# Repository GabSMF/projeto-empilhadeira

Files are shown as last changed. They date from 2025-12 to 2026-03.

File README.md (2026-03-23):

# Robotics - Autonomous Fork-Lif Project
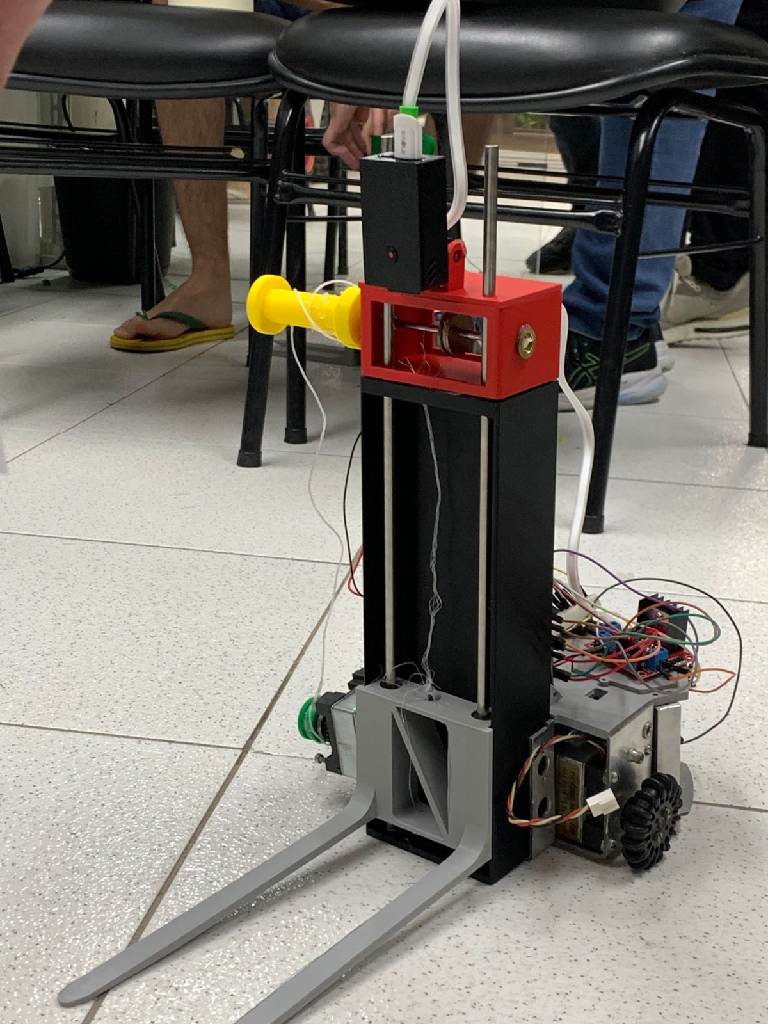
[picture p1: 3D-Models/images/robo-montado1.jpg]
robo montado irl


## 3D Pieces
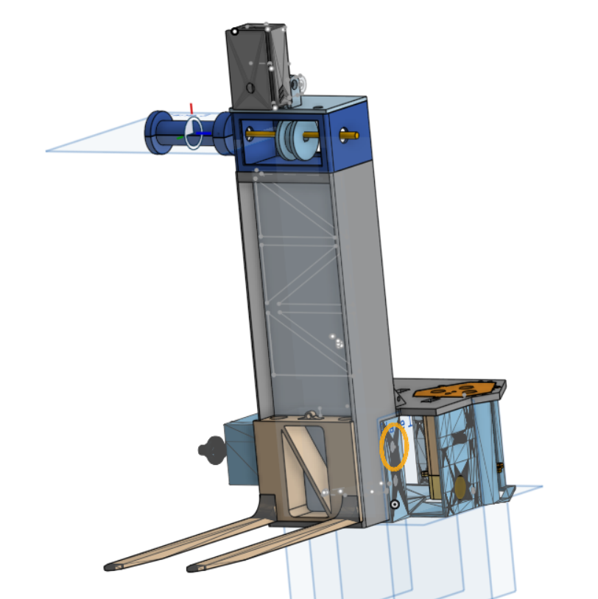
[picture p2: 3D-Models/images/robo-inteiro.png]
robo inteiro 3d


### 1. Chassis Cover

The **chassis cover** is the central interface piece between the metal chassis and the 3D printed modules.

**Function and characteristics:**
- Fixed directly to the **metal chassis** using screws.
- Has **2 holes** for fitting the **battery holders** (battery cases).
- On the front, there is a **protrusion/overlap** where the connection with the **elevator guide** is made, through **3 holes** for screws that ensure the guide is fixed.
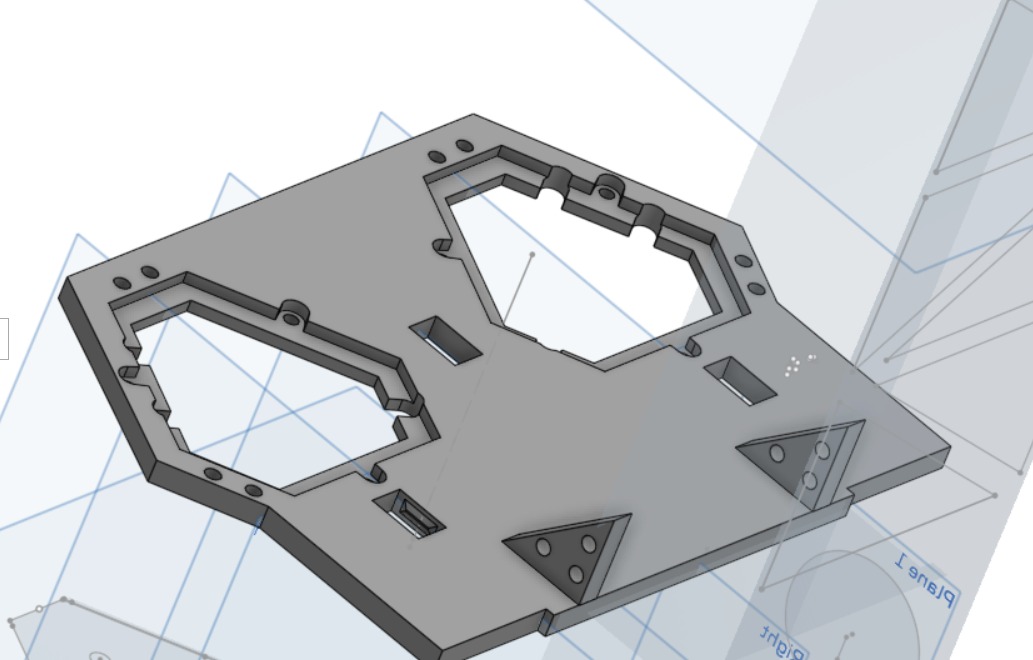
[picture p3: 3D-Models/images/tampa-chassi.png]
Tampa

---

### 2. Fork Guide

The **fork guide** is responsible for guiding the vertical movement of the fork along the **Y** axis.

**Function and characteristics:**
- It has slots for **2 metal cylinders** that function as **guide shafts**.
- The fork uses **linear bearings** (minimum 2, 6 mm inner diameter) that slide on these shafts.
- On the top, there is:
  - A **hole for the passage of the wire/cable** coming from the pulley.
  - Slots for the **pulley housing**, which houses the pulley and the shaft.
  - On the lower side there is a region intended for fixing the **lateral motor**, responsible for driving the fork pulley (see photos of the assembled robot for reference).

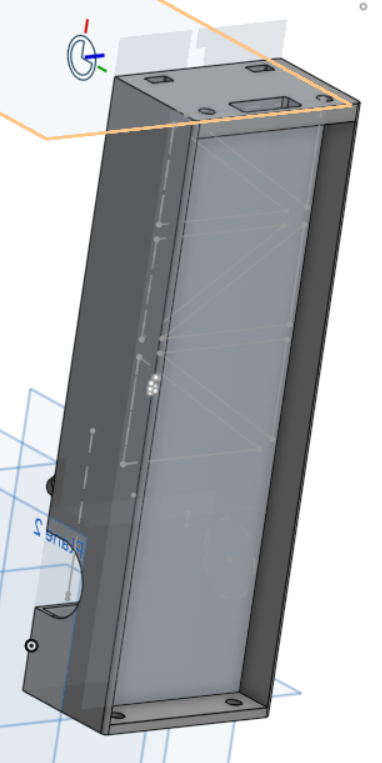
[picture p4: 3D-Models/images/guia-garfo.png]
Guia Garfo

---

### 3. Fork

The **fork** is the component that effectively interacts with the pallet, performing the loading.

**Function and characteristics:**
- It has **vertical sections** for fitting at least **2 linear bearings**, which allow smooth sliding on the guide axes.
- It includes a **specific region for tying/fixing the pulley cable**, responsible for raising and lowering the fork.

**Points observed / future improvements:**
- The **height of the fork**, in the current configuration, is **above the height of the pallet**, which may hinder ideal fitting.
- The **thickness of the fork** is relatively **thin**, which may compromise robustness and mechanical resistance.
- Suggested improvements: reinforce the cross-section and adjust the height to better align with the height of the pallet.
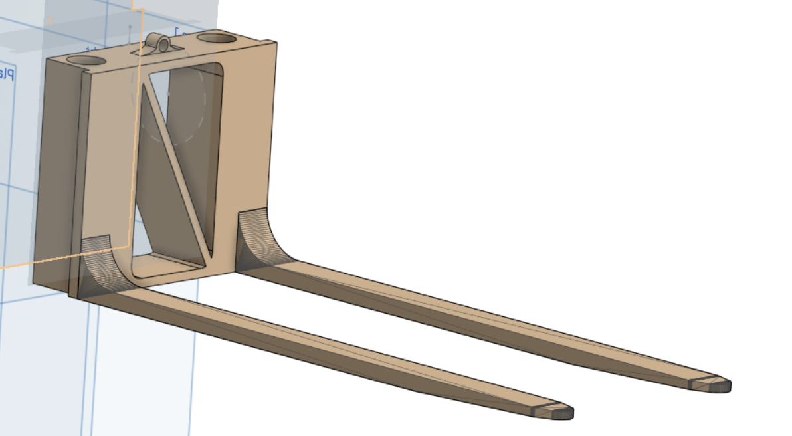
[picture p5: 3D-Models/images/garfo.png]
Garfo


---

### 4. Pulley Housing

The **pulley housing** is mounted on the upper part of the **fork guide** and houses the fork's drive system.

**Function and characteristics:**
- It has side slots for **bearings**, where a **shaft** is inserted that rotates the **inner pulley**, responsible for raising/lowering the fork.
- Due to the limited length of the available metal shaft, it was necessary to create a **3D shaft extender**, composed of **two pieces (male and female)** that fit together.
- This extender "embraces" an **outer pulley** of the same size as the inner pulley.

**Problems and lessons learned:**
- The **excessive lateral space** on one side of the pulley was not considered, which impacted the ideal fit.
- The fit did not take into account the **pulley fixing screw on the shaft**, which made correct assembly difficult.
**Case lid and camera mount:**
- A fitting inspired by **GoPro mounts** was created on the case lid to attach the **ESP32-CAM case**.
- However, the path of the **metal shafts** that pass through this area was not considered, which made it difficult to pass the screw and thread to secure the camera to the mount.
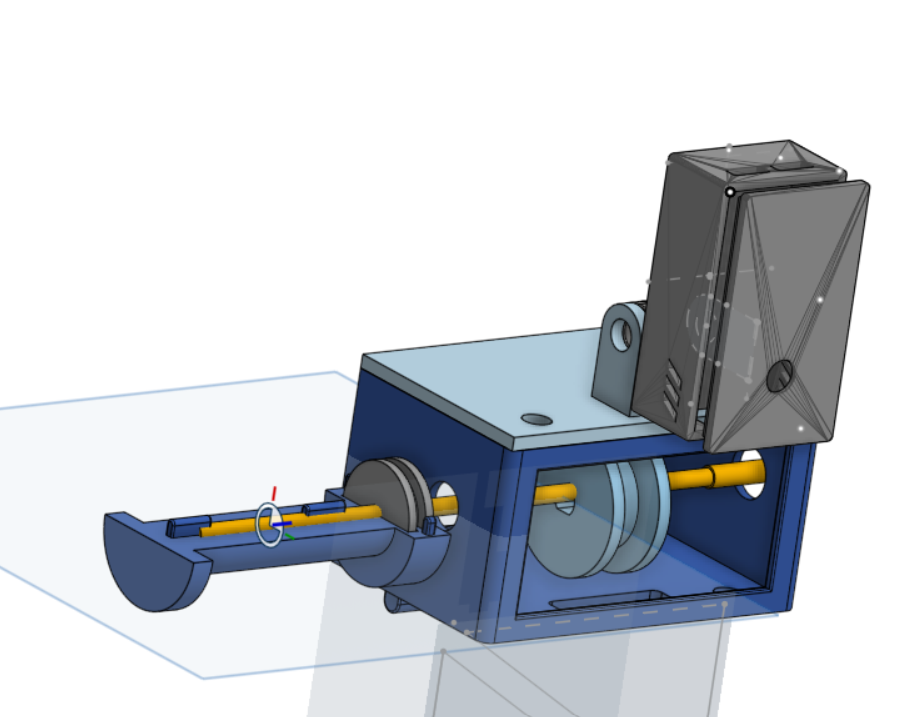
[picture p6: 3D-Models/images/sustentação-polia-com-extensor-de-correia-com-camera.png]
caixa polia

---

### 5. ESP32-CAM Enclosure

The **ESP32-CAM enclosure** was one of the project's greatest successes.

**Function and characteristics:**
- Virtually **perfect** fit for an **ESP32-S3** module (version with **2 USB-C ports**).
- Features **ventilation openings** to aid in heat dissipation.
  
**Points of attention / improvements:**
- In the long term, the current ventilation openings may be **insufficient** for continuous use in higher heat scenarios.
- Suggestion: enlarge the ventilation area or add more holes/grilles to the lid. mais furos/grelhas na tampa.

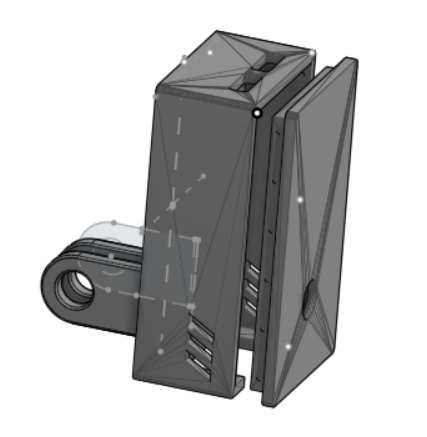
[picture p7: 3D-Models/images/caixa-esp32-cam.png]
Caixa ESP32-Cam

---

### 6. Battery Case

The **battery case** is responsible for housing the robot's power batteries.

**Function and characteristics:**
- Sized to hold **3 batteries**.
- Fits onto the **chassis cover**, remaining **suspended**, with holes for **screws and nuts** to secure it.
- Has a **screwable bottom cover**, allowing access to the batteries for replacement or maintenance.

**Points for improvement:**
- Internally, it would be beneficial to include, on the top, a **modeled area for electrical connection tracks or supports**, allowing for:
- Cleaner organization of contacts.
- Reduction in the use of **loose wires or springs**.
- Easier assembly and maintenance of the battery pack.

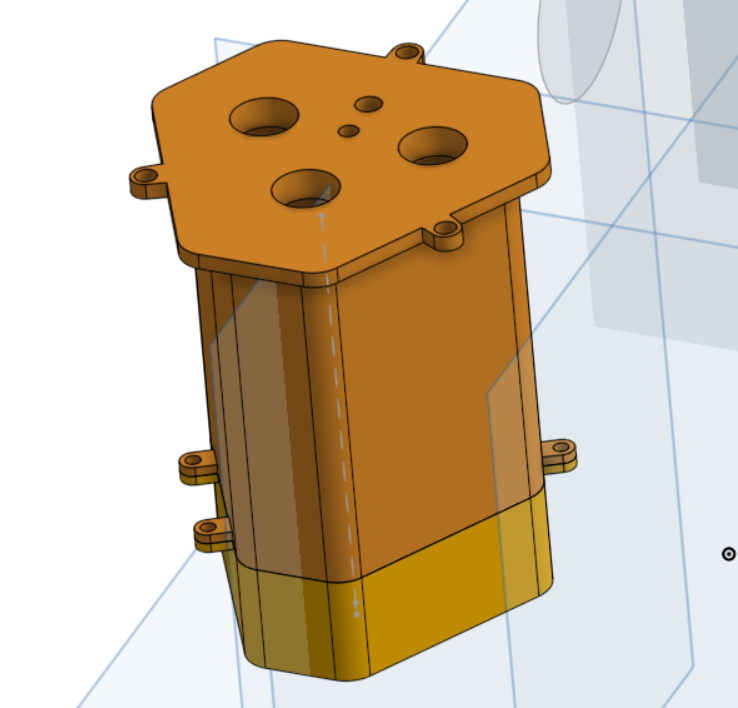
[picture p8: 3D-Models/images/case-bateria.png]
Case Bateria

---

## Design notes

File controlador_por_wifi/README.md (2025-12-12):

# Controlador por WiFi

Este diretório contém a versão final e testes do controlador do robô acessível via rede WiFi.

## Arquivos

### `controlador_por_wifi.ino`
Versão principal e funcional do firmware do robô.
- **Funcionalidade**: Cria um WebServer no ESP32 que aceita comandos POST.
- **Integração**: Combina a lógica de `controle_sem_pid` com o servidor web.
- **Uso**: Recebe comandos (ex: `F200`, `U255`) na rota `/command` e aciona os motores.

### `controla_wifi_testando_RPM_TABLE`
Tentativa de calibração manual via tabela de RPM.
- **Objetivo**: Mapear valores de PWM para corrigir diferenças entre os motores e andar em linha reta.
- **Resultado**: **Descartado**. A calibração feita em bancada não se sustentou no chão devido à variação de carga e atrito com o peso da estrutura.

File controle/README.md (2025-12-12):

# Controle do Robô

Este diretório contém os códigos de teste e desenvolvimento da lógica de movimentação do robô via Serial.

## Arquivos

### `controle_sem_pid`
Implementação funcional do controle básico do robô via comandos na porta Serial.
- **Comandos**: `F` (Frente), `B` (Trás), `L` (Esquerda), `R` (Direita), `U` (Subir Lift), `D` (Descer Lift), `P`/`S` (Parar).
- **Lógica**: Controle direto via PWM sem malha fechada.
- **Status**: **Funcional**. Base para a versão WiFi.

### `controle_com_pid`
Tentativa de implementação de controle PID para garantir movimento retilíneo.
- **Objetivo**: Usar encoders para equalizar a velocidade das rodas.
- **Resultado**: **Descartado**. Os encoders disponíveis mostraram-se muito imprecisos para um ajuste fino eficaz.

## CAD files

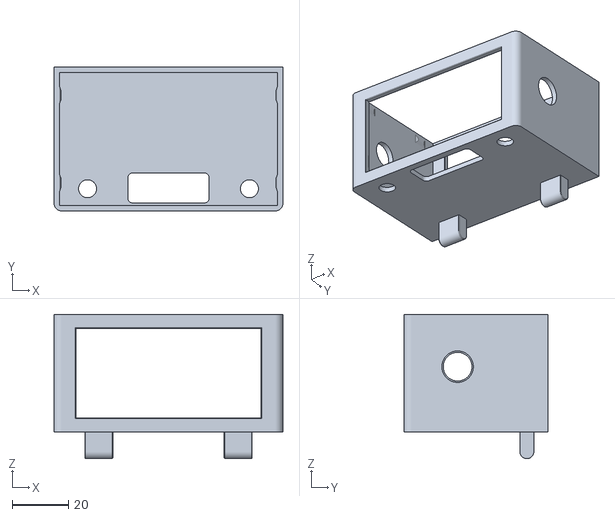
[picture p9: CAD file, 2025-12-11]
3D-Models/caixa-sustentação-polia.stl
81.7 x 51.3 x 51.5

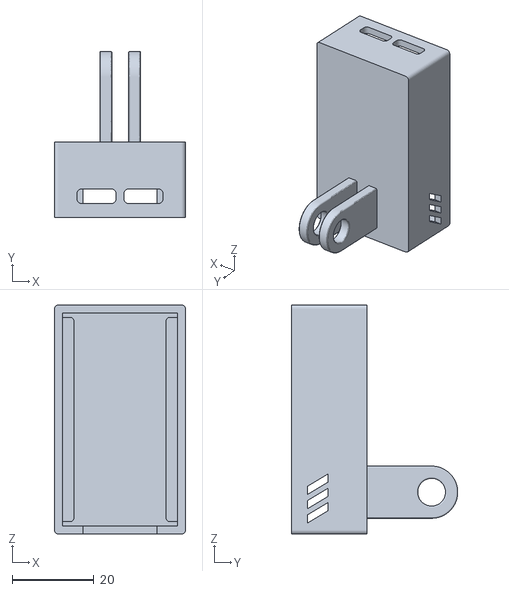
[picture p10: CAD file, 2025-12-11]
3D-Models/caixa-camera-esp32cam.stl
32.1 x 40.7 x 56.0

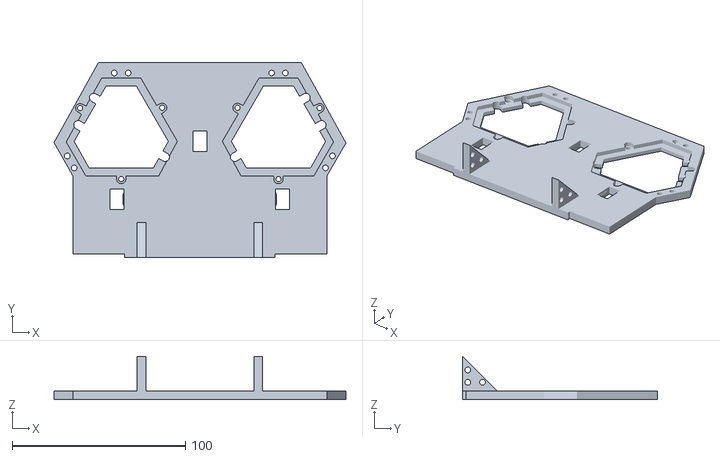
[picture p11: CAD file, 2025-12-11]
3D-Models/base-final.stl
168.3 x 112.3 x 25.0

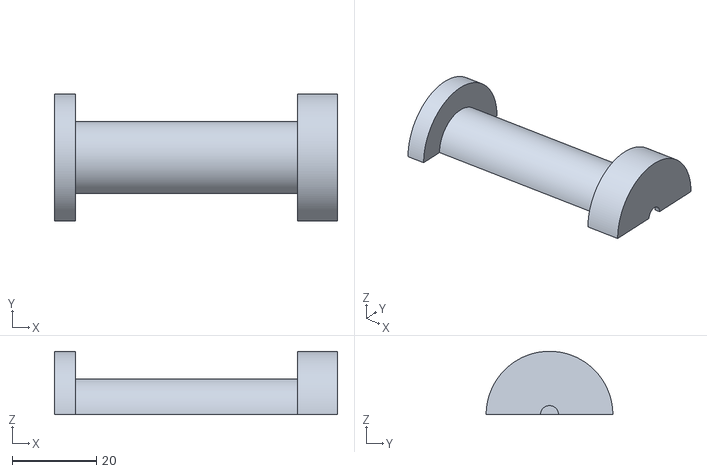
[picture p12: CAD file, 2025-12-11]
3D-Models/extensor-correia-femea.stl
67.0 x 30.0 x 15.0

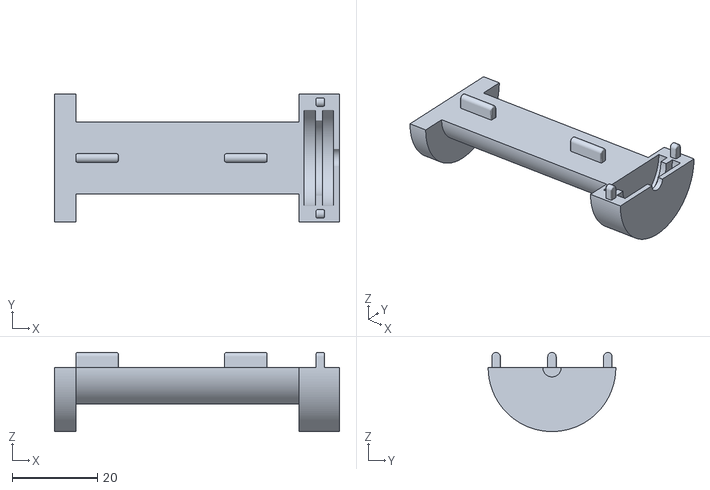
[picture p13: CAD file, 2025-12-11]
3D-Models/extensor-femea-macho.stl
67.0 x 30.0 x 18.6

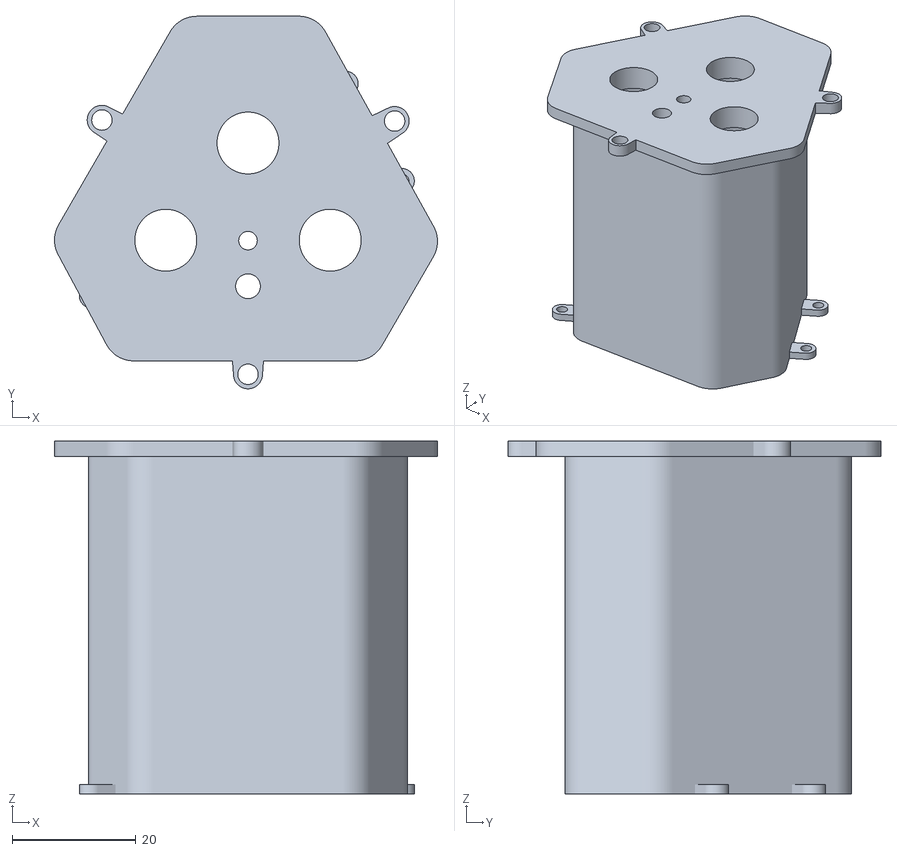
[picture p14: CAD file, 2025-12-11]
3D-Models/case-bateria-final.stl
61.9 x 60.2 x 57.0

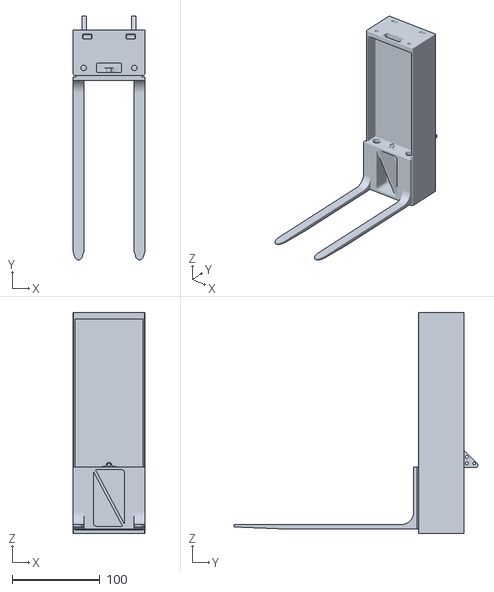
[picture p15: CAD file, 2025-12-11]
3D-Models/garfo-final.stl
82.3 x 278.2 x 252.0

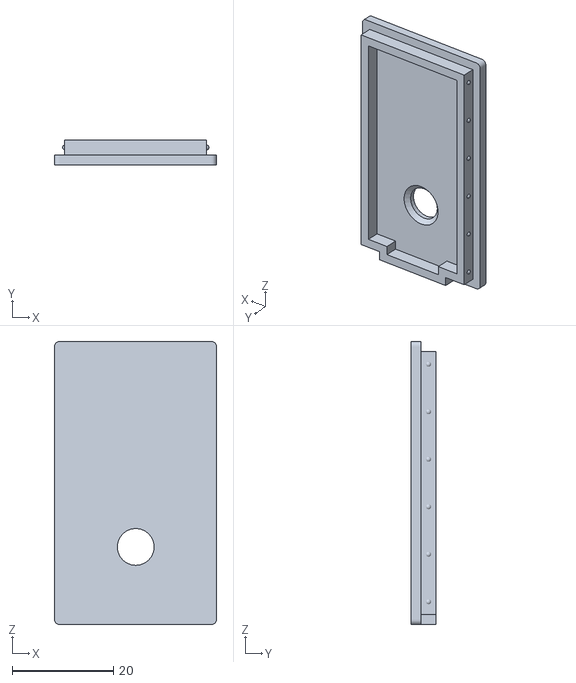
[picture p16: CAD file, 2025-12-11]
3D-Models/tampa-caixa-esp32-cam.stl
32.1 x 5.00 x 56.0

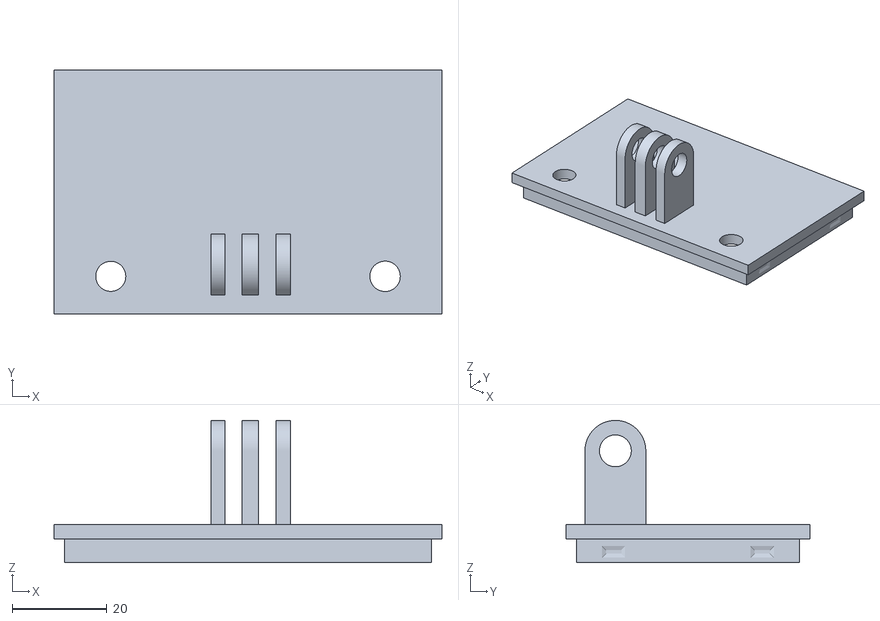
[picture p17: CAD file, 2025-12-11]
3D-Models/tampa-caixa-sustentação-polia.stl
81.7 x 51.3 x 29.9

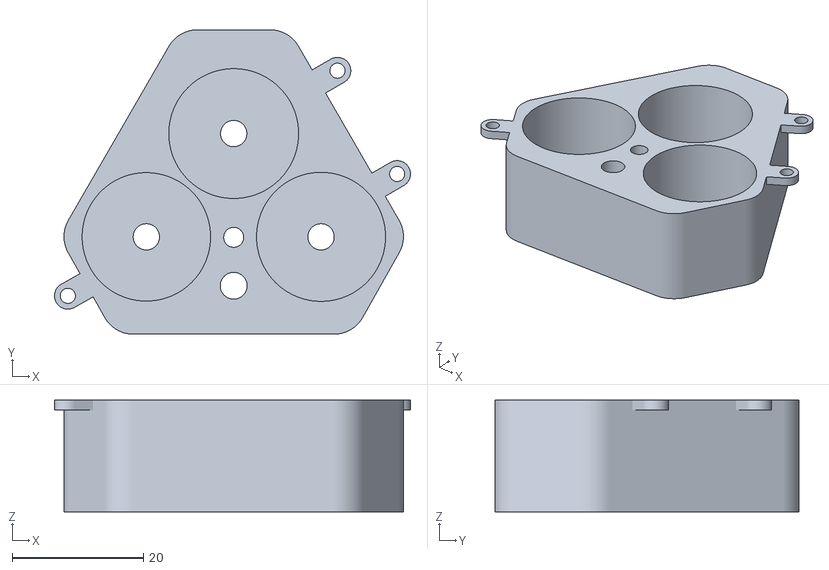
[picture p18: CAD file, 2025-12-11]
3D-Models/tampa-case-bateria.stl
54.2 x 46.3 x 17.0

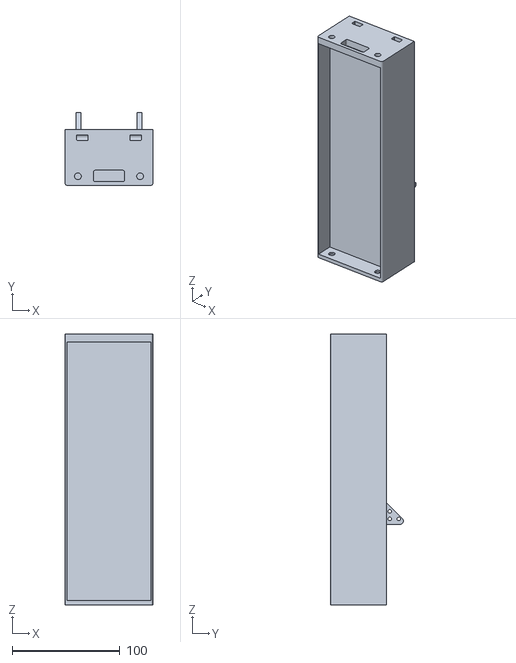
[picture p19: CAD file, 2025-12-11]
3D-Models/guia-garfo-final.stl
81.7 x 67.8 x 252.0

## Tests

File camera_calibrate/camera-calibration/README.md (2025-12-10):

# Camera Calibration
This repository contains a code that can be used to calibrate an ESP32 camera. The implementation of the `cam` package that is used here to get frames from the camera may or may not need to be modified to comply to the camera you are using.

## Installation
After cloning the repository simply run `pip install -r requirements.txt` and you're all set to go.

## Running demonstration
Run script `calibration.py` - it will take all the example images from `screenshots/` directory and perform a camera calibration based on them. After the calibration the program will draw a raw realtime stream of frames from the camera and below it a rectified version of the same stream after applying the calibration.

## Performing the Calibration
First off you need to print the [chessboard calibration pattern](calib_pattern.pdf). Then run the `image_capture.py` script and using spacebar capture around 20 images of the chessboard from different angles and using different parts of the camera screen. These images will be saved to `screenshots/` directory which already contains a few sample images of the chessboard, so if you want to run a calibration only based on your new images you have to delete them prior to this. Secondly run `calibration.py`. All the images used for the calibration will be displayed one by one with the chessboard pattern drawn on them. After this process you will get stream of frames from your calibrated camera side-by-side to the image from before the calibration for comparison.

## Example
Below are presented images used for calibration:






















After running `calibration.py` on those images we get side-by-side view of images before and after calibration (difference is barely visible because the camera used here had already pretty good image prior to calibration):

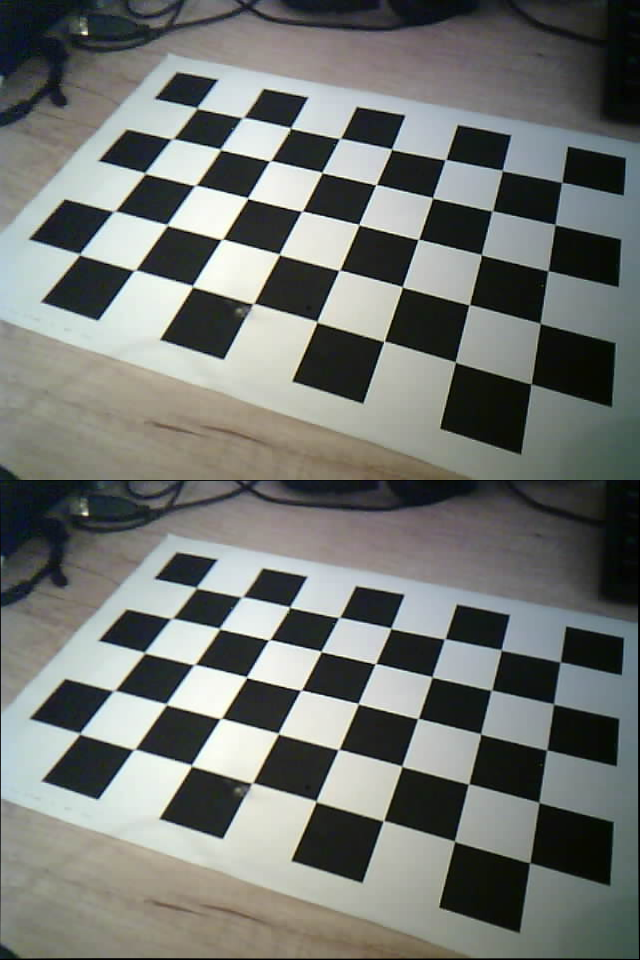
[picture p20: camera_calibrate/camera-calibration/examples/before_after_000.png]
before_after_000

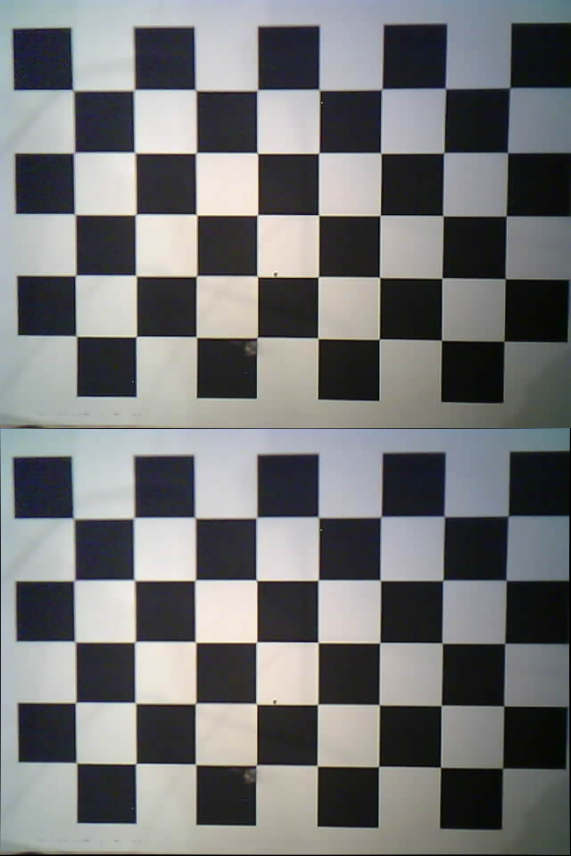
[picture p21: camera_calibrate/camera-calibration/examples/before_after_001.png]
before_after_001

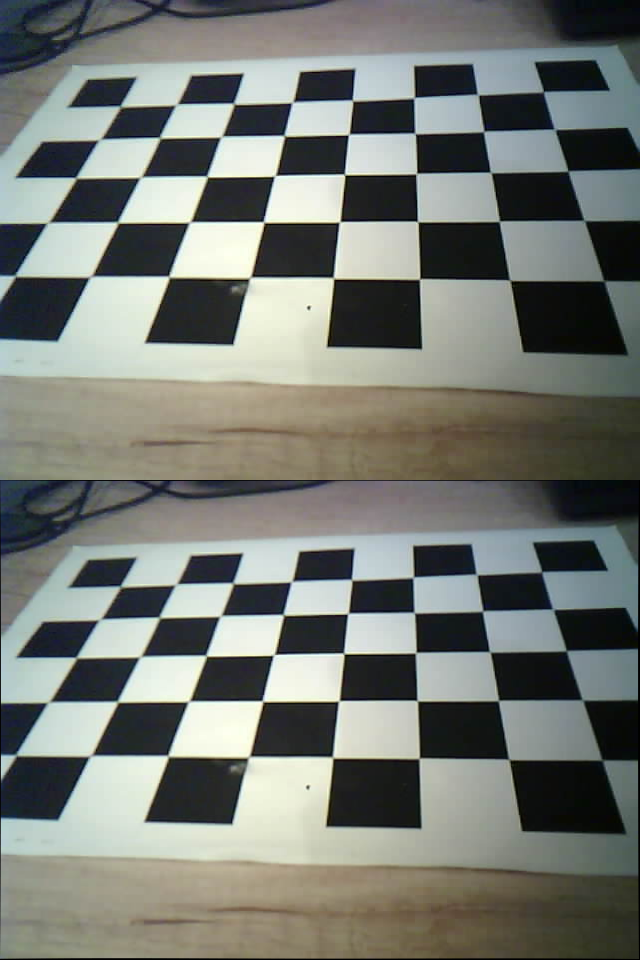
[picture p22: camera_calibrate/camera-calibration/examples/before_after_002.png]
before_after_002

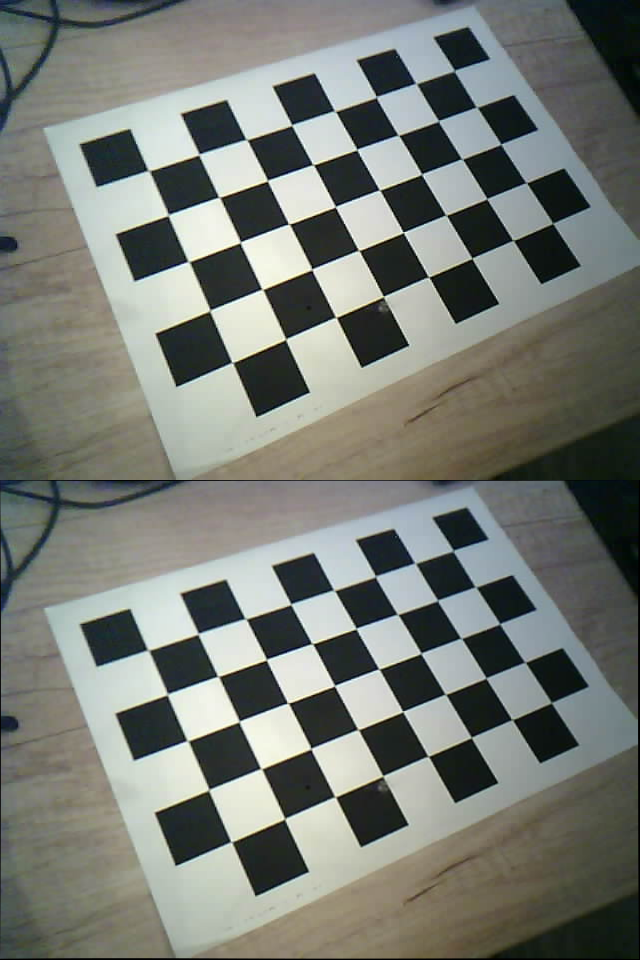
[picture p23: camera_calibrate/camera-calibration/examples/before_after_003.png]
before_after_003

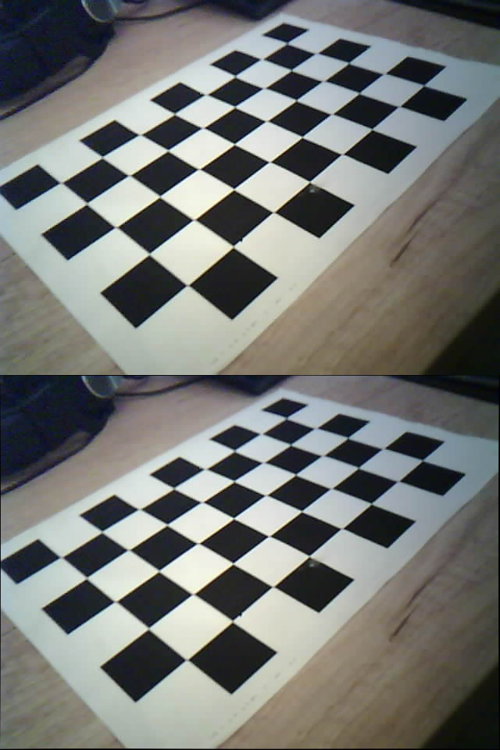
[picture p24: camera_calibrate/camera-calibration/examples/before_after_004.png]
before_after_004

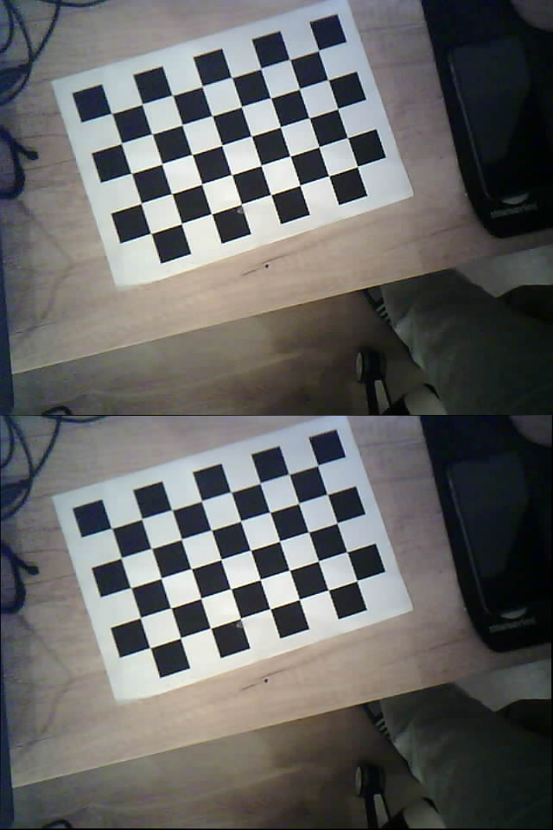
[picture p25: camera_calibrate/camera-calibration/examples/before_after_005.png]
before_after_005

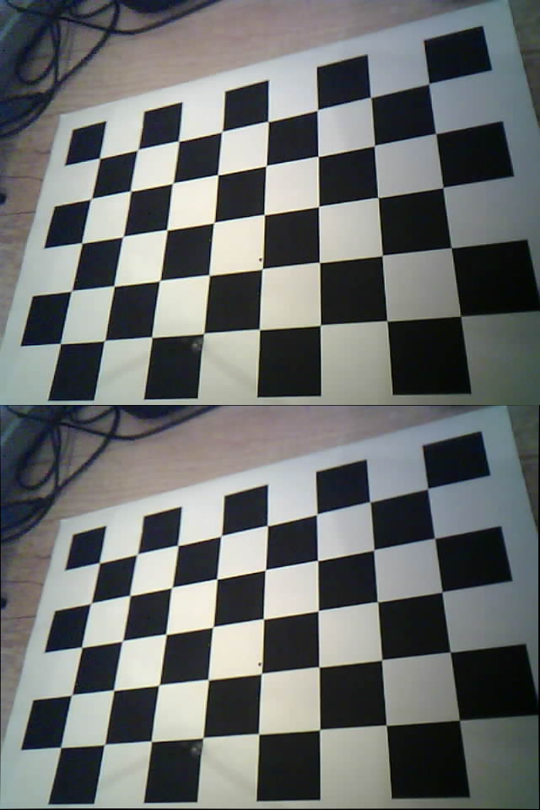
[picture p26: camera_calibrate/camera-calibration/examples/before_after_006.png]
before_after_006

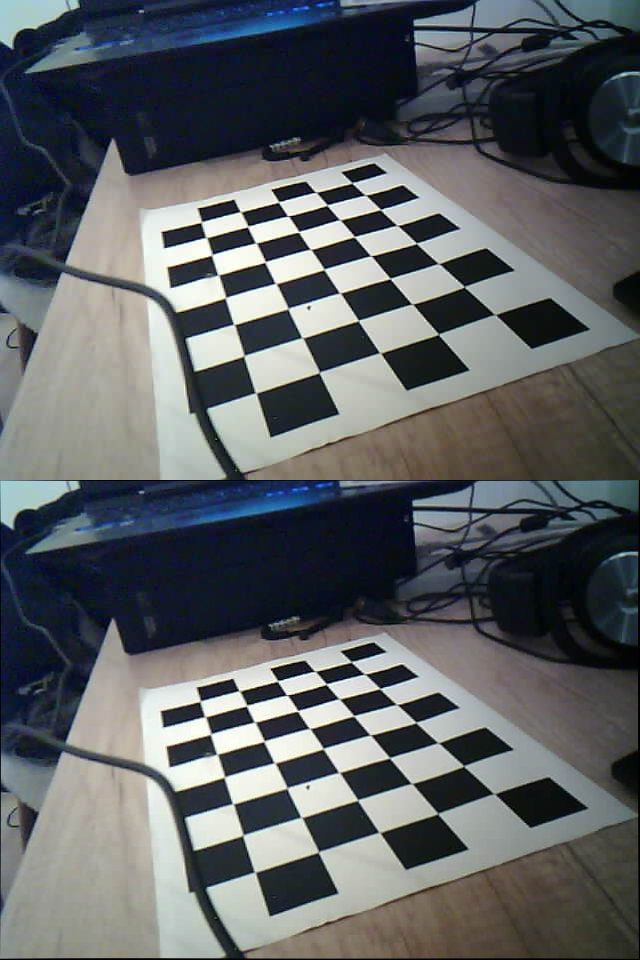
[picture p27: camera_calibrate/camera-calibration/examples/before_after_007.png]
before_after_007

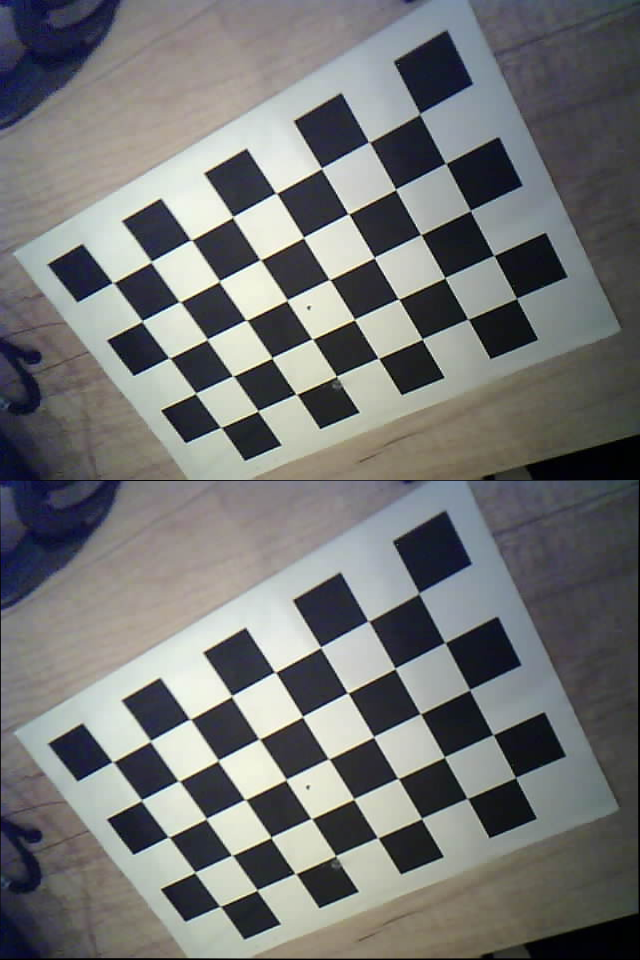
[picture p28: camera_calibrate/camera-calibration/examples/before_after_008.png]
before_after_008

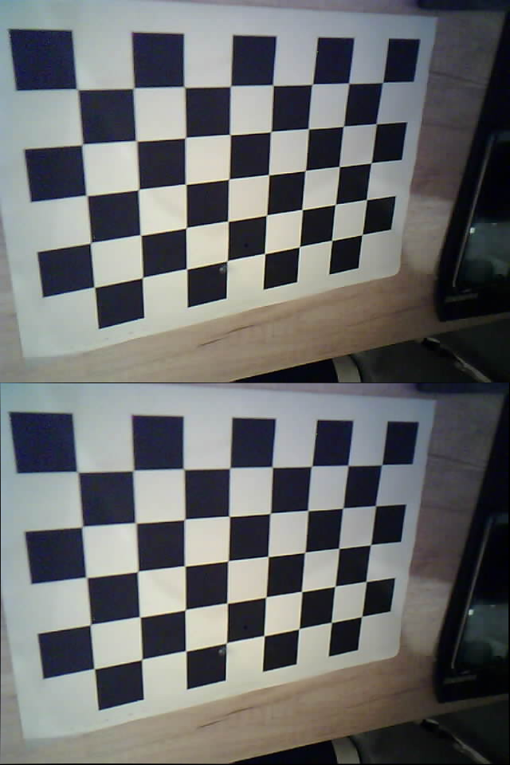
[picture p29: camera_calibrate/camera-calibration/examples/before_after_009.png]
before_after_009

# camera_calibration

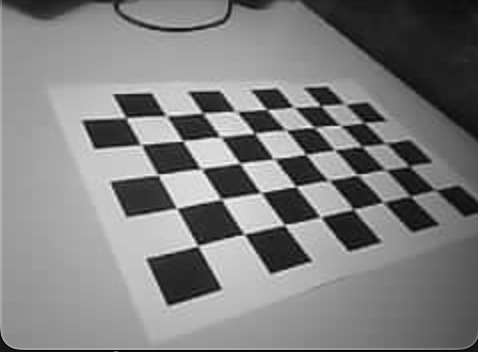
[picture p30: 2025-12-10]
camera_calibrate/camera-calibration/screenshots/Screenshot 2025-11-25 at 15.29.17.png

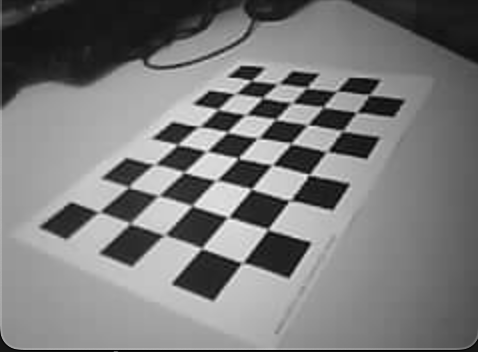
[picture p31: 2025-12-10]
camera_calibrate/camera-calibration/screenshots/Screenshot 2025-11-25 at 15.28.42.png

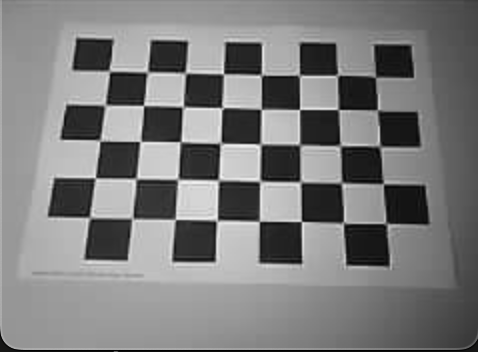
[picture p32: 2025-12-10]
camera_calibrate/camera-calibration/screenshots/Screenshot 2025-11-25 at 15.26.39.png

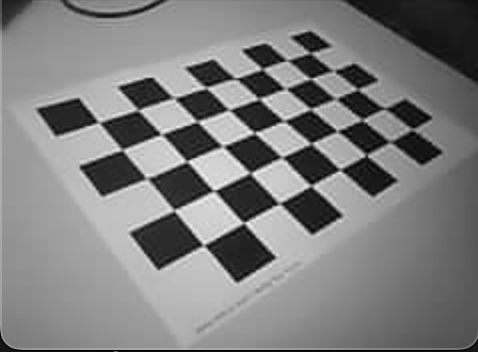
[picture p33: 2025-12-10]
camera_calibrate/camera-calibration/screenshots/Screenshot 2025-11-25 at 15.28.14.png

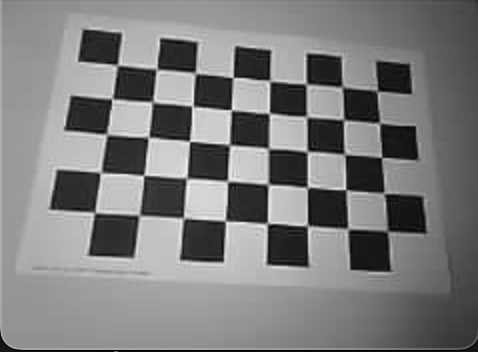
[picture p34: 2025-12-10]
camera_calibrate/camera-calibration/screenshots/Screenshot 2025-11-25 at 15.26.48.png

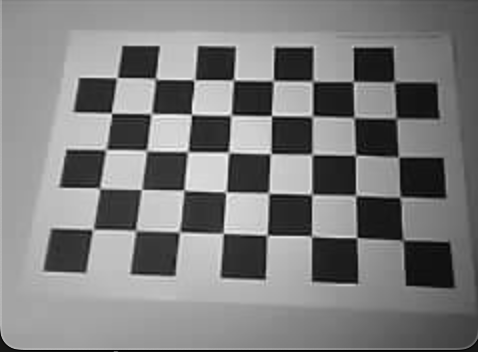
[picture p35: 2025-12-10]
camera_calibrate/camera-calibration/screenshots/Screenshot 2025-11-25 at 15.29.40.png

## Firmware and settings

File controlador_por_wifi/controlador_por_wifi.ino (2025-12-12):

#include <Arduino.h>
#include <WebServer.h>
#include <WiFi.h>

/*
Codigo para que o servidor web receba os comandos via POST e os envie para o robo.
Comandos como 'F200', 'S', 'U255' podem ser enviados pelo client do computador, qque serve como
controle remoto.


*/

// --- CONFIGURAÇÕES WIFI ---
const char *ssid = "Projeto";
const char *password = "2022-11-07";

WebServer server(80);

// --- PINOS MOTORES DE TRAÇÃO ---
// Motor 1 (Esquerdo)
#define PINO_IN1 22
#define PINO_IN2 23
#define PINO_PWM 18

// Motor 2 (Direito)
#define PINO_IN3 19
#define PINO_IN4 21
#define PINO_PWM2 17

// --- PINOS MOTOR LIFT (EMPILHADEIRA) ---
#define PINO_IN5 33     // Controle sentido A (Lift)
#define PINO_IN6 32     // Controle sentido B (Lift)
#define PINO_PWM_LIFT 4 // Velocidade (Lift)

// Variáveis globais
char comandoAtual = 'P'; // Começa Parado
int velocidadeAtual = 0;

// Forward declarations of helper functions
void moverFrente(int pwm);
void moverTras(int pwm);
void virarEsquerda(int pwm);
void virarDireita(int pwm);
void pararRodas();
void moverLiftCima(int pwm);
void moverLiftBaixo(int pwm);
void pararLift();
void pararTudo();
void executarComando();

// --- HANDLER DO SERVIDOR WEB ---
void handlePostCommand() {
  if (server.hasArg("plain")) {
    String body = server.arg("plain");
    body.trim(); // Remove whitespace

    Serial.println("Recebido via POST: " + body);

    if (body.length() > 0) {
      char cmd = body.charAt(0);

      // Tenta ler a velocidade se houver
      int novaVelocidade = 0;
      if (body.length() > 1) {
        novaVelocidade = body.substring(1).toInt();
      }

      comandoAtual = cmd;

      // Atualiza velocidade se foi enviado um valor maior que 0
      if (novaVelocidade > 0) {
        velocidadeAtual = novaVelocidade;
      }

      // Trava de segurança PWM
      if (velocidadeAtual > 255)
        velocidadeAtual = 255;
      if (velocidadeAtual < 0)
        velocidadeAtual = 0;

      executarComando();

      server.send(200, "text/plain",
                  "Comando Executado: " + String(comandoAtual) +
                      " Vel: " + String(velocidadeAtual));
    } else {
      server.send(400, "text/plain", "Comando vazio");
    }
  } else {
    server.send(400, "text/plain", "POST sem corpo");
  }
}

void setup() {
  Serial.begin(115200);

  // Configura Tração
  pinMode(PINO_IN1, OUTPUT);
  pinMode(PINO_IN2, OUTPUT);
  pinMode(PINO_PWM, OUTPUT);

  pinMode(PINO_IN3, OUTPUT);
  pinMode(PINO_IN4, OUTPUT);
  pinMode(PINO_PWM2, OUTPUT);

  // Configura Lift
  pinMode(PINO_IN5, OUTPUT);
  pinMode(PINO_IN6, OUTPUT);
  pinMode(PINO_PWM_LIFT, OUTPUT);

  pararTudo();

  // Conexão WiFi
  WiFi.begin(ssid, password);
  Serial.print("Conectando ao Wi-Fi...");
  while (WiFi.status() != WL_CONNECTED) {
    delay(500);
    Serial.print(".");
  }

  Serial.println("\nConectado!");
  Serial.print("IP Address: ");
  Serial.println(WiFi.localIP());

  // Rota POST
  server.on("/command", HTTP_POST, handlePostCommand);

  server.begin();
  Serial.println("HTTP server iniciado!");
  Serial.println("Envie POST para /command com corpo ex: 'F200', 'S', 'U255'");
}

void loop() { server.handleClient(); }

void executarComando() {
  switch (comandoAtual) {
  // --- COMANDOS DE TRAÇÃO ---
  case 'F':      // FRENTE
    pararLift(); // Garante que o lift pare
    moverFrente(velocidadeAtual);
    Serial.println("RODAS: Frente");
    break;

  case 'B': // RÉ
    pararLift();
    moverTras(velocidadeAtual);
    Serial.println("RODAS: Tras");
    break;

  case 'L': // ESQUERDA
    pararLift();
    virarEsquerda(velocidadeAtual);
    Serial.println("RODAS: Esq");
    break;

  case 'R': // DIREITA
    pararLift();
    virarDireita(velocidadeAtual);
    Serial.println("RODAS: Dir");
    break;

  // --- COMANDOS DO LIFT ---
  case 'U':       // UP (SUBIR)
    pararRodas(); // Garante que o carro pare
    moverLiftCima(velocidadeAtual);
    Serial.println("LIFT: Subindo");
    break;

  case 'D': // DOWN (DESCER)
    pararRodas();
    moverLiftBaixo(velocidadeAtual);
    Serial.println("LIFT: Descendo");
    break;

  // --- COMANDO DE PARADA ---
  case 'S':
  case 'P':
    Serial.println("PARADA TOTAL");
    pararTudo();
    velocidadeAtual = 0;
    break;

  default:
    // Comando desconhecido, ignora.
    Serial.println("Comando desconhecido: " + String(comandoAtual));
    break;
  }
}

// ==========================================
// --- FUNÇÕES AUXILIARES ---
// ==========================================

// --- Funções das Rodas ---
void moverFrente(int pwm) {
  digitalWrite(PINO_IN1, HIGH);
  digitalWrite(PINO_IN2, LOW);
  analogWrite(PINO_PWM, pwm);
  digitalWrite(PINO_IN3, LOW);
  digitalWrite(PINO_IN4, HIGH);
  analogWrite(PINO_PWM2, pwm);
}

void moverTras(int pwm) {
  digitalWrite(PINO_IN1, LOW);
  digitalWrite(PINO_IN2, HIGH);
  analogWrite(PINO_PWM, pwm);
  digitalWrite(PINO_IN3, HIGH);
  digitalWrite(PINO_IN4, LOW);
  analogWrite(PINO_PWM2, pwm);
}

void virarEsquerda(int pwm) {
  digitalWrite(PINO_IN1, LOW);
  digitalWrite(PINO_IN2, HIGH);
  analogWrite(PINO_PWM, pwm);
  digitalWrite(PINO_IN3, LOW);
  digitalWrite(PINO_IN4, HIGH);
  analogWrite(PINO_PWM2, pwm);
}

void virarDireita(int pwm) {
  digitalWrite(PINO_IN1, HIGH);
  digitalWrite(PINO_IN2, LOW);
  analogWrite(PINO_PWM, pwm);
  digitalWrite(PINO_IN3, HIGH);
  digitalWrite(PINO_IN4, LOW);
  analogWrite(PINO_PWM2, pwm);
}

void pararRodas() {
  digitalWrite(PINO_IN1, LOW);
  digitalWrite(PINO_IN2, LOW);
  analogWrite(PINO_PWM, 0);
  digitalWrite(PINO_IN3, LOW);
  digitalWrite(PINO_IN4, LOW);
  analogWrite(PINO_PWM2, 0);
}

// --- Funções do Lift ---
void moverLiftCima(int pwm) {
  digitalWrite(PINO_IN5, HIGH);
  digitalWrite(PINO_IN6, LOW);
  analogWrite(PINO_PWM_LIFT, pwm);
}

void moverLiftBaixo(int pwm) {
  digitalWrite(PINO_IN5, LOW);
  digitalWrite(PINO_IN6, HIGH);
  analogWrite(PINO_PWM_LIFT, pwm);
}

void pararLift() {
  digitalWrite(PINO_IN5, LOW);
  digitalWrite(PINO_IN6, LOW);
  analogWrite(PINO_PWM_LIFT, 0);
}

// --- Parada Geral ---
void pararTudo() {
  pararRodas();
  pararLift();
}

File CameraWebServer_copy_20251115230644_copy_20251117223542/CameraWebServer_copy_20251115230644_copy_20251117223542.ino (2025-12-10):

#include "esp_camera.h"
#include <WiFi.h>

// ===========================
// WiFi credentials
// ===========================
const char *ssid = "Projeto";
const char *password = "2022-11-07";

void startCameraServer();
void setupLedFlash();

void setup() {
  Serial.begin(115200);
  Serial.setDebugOutput(true);
  Serial.println();
  
  camera_config_t config = {
    .pin_pwdn = -1, 
    .pin_reset = -1,
    .pin_xclk = 15, 
    .pin_sscb_sda = 4,
    .pin_sscb_scl = 5,
    .pin_d7 = 16, 
    .pin_d6 = 17,
    .pin_d5 = 18, 
    .pin_d4 = 12,
    .pin_d3 = 10, 
    .pin_d2 = 8,
    .pin_d1 = 9, 
    .pin_d0 = 11,
    .pin_vsync = 6, 
    .pin_href = 7,
    .pin_pclk = 13,
    .xclk_freq_hz = 20000000,
    .ledc_timer = LEDC_TIMER_0,
    .ledc_channel = LEDC_CHANNEL_0,

    // *** IMPORTANTE ***
    // GRAYSCALE, resolução baixa (QVGA)
    .pixel_format = PIXFORMAT_GRAYSCALE,
    .frame_size = FRAMESIZE_HQVGA,

    // Só funciona com JPEG, então deixado comentado
    // .jpeg_quality = 10,
    
    .fb_count = 2,
    .grab_mode = CAMERA_GRAB_LATEST
  };
  
  // camera init
  esp_err_t err = esp_camera_init(&config);
  if (err != ESP_OK) {
    Serial.printf("Camera init failed with error 0x%x", err);
    return;
  }

  // ==========================
  // Ajustes do sensor
  // ==========================
  sensor_t *s = esp_camera_sensor_get();

  // Contraste (-2 a +2)
  s->set_contrast(s, -2);  // 2 = contraste alto

  // Brilho (-2 a +2)
  s->set_brightness(s, 0); // leve aumento de brilho

  // Saturação (-2 a +2) — sem efeito em grayscale, mas seguro
  s->set_saturation(s, -2);

  // Special Effect (0=none, 2=grayscale)
  // Você já está usando grayscale nativo, então deixar none
  s->set_special_effect(s, 0);

  // Obs: s->set_quality() só funciona com JPEG
  // Como você está usando GRAYSCALE, jpeg_quality não é usado.

  // ==========================
  // WiFi
  // ==========================
  WiFi.begin(ssid, password);
  WiFi.setSleep(false);

  Serial.print("WiFi connecting");
  while (WiFi.status() != WL_CONNECTED) {
    delay(500);
    Serial.print(".");
  }
  Serial.println("");
  Serial.println("WiFi connected");

  startCameraServer();

  Serial.print("Camera Ready! Use 'http://");
  Serial.print(WiFi.localIP());
  Serial.println("' to connect");
}

void loop() {
  delay(10000);
}

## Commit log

2025-11-11 Implement initial QR Code detection with OpenCV
    This code initializes video capture and implements QR code detection using OpenCV on a Raspberry Pi. It includes various processing modes and saves the output to a video file.
2025-11-11 Add minimal encoder reading example
2025-11-11 Implement RPM calculation and output
    Added RPM calculation and printing to the serial monitor.
2025-11-11 Initialize motor control pins in ponteH_duas_rodas
    DUas rodas girando para mesma direcao, ainda nao tem encoder na segunda roda
2025-11-11 Implementando leitura de qr code com placa mh-et
2025-11-18 Add motor control setup for Arduino
2025-11-26 Add PID control for dual motor system
    This file contains the implementation of a PID controller for a dual motor system using Arduino. It includes setup for motor control, encoder reading, and a main loop for processing RPM and applying 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
2025-12-02 inicio servidor flask para controlar robô
2025-12-04 versao codigo esp pid controlado por wifi, e versao de flask servidor) por conexao de wifi ao esp (rede da puc)
2025-12-10 adicionando comandos de serial U e D do motor de lift (empilhadeira)
2025-12-10 Swap left and right motor enable pin definitions and reset ramp and integral error variables on stop command.
2025-12-10 teste de controle com flag para STOP
2025-12-10 Adicionando codigos e projetos da camera e controle via requisicoes POST no esp de controle dos motores para futura integracao
    [partitions.csv]
2025-12-10 versao do controle sem pid
2025-12-11 Adicionando projeto de controle next
2025-12-11 STLs e Imagens finais
    [base-final.stl, caixa-camera-esp32cam.stl, caixa-sustentação-polia.stl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]
